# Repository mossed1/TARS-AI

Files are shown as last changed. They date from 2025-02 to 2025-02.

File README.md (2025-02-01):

<h1 align="center">TARS-AI</h2>

<p align="center">
    <a href="https://discord.gg/AmE2Gv9EUt">
      
    </a>
    <a href="https://www.youtube.com/@TARS-AI.py.youtube">
        
    </a>
    <a href="https://www.instagram.com/tars.ai.py">
        
    </a>
    <a href="https://www.tiktok.com/@tars.ai.py">
        
    </a>
</p>

<p align="center"></p>

A recreation of the TARS robot from Interstellar, featuring AI capabilities and servo-driven movement. 

## Table of Contents
- [Hardware Requirements](#hardware-requirements)
- [Software Stack](#software-stack)
- [Build Modifications](#build-modifications)
- [License](#license)
- [Contributing](#contributing)
- [Additional Resources](#additional-resources)

## Hardware Requirements 

Everything here is **under development** and is subject to change.
The buck converter and USB power modules are the most important power components and there are many options depending on your build choices. If you have any questions ping us in the discord electrical channel.

| Category | Component | Description | Link |
|---|---|---|---|
| **Printing** | Bambu Labs Printer | Compatible models: P1S, A1, X1C | - |
| | TPU Filament (Bambu) | For all "Flexor" parts | [Buy](https://us.store.bambulab.com/products/tpu-for-ams) |
| | TPU Filament (Alternative) | Overture TPU filament | [Buy](https://www.amazon.com/Overture-Filament-Flexible-Consumables-Dimensional/dp/B07VDP2S3P/) |
| | PETG Filament | For all non-Flexor parts | [Buy](https://us.store.bambulab.com/products/petg-hf) |
| | PLA Filament | Optional - for rapid prototyping | - |
| **Core Components** | Raspberry Pi 5 | Main computing unit | [Buy](https://www.amazon.com/Raspberry-Pi-Quad-core-Cortex-A76-Processor/dp/B0CTQ3BQLS/) |
| | 3.5" LCD Display | Interface display | [Buy](https://www.amazon.com/OSOYOO-3-5inch-Display-Protective-Raspberry/dp/B09CD9W6NQ/) |
| | 16-Channel PWM Servo Driver | I2C Interface | [Buy](https://www.amazon.com/gp/product/B00EIB0U7A/) |
| **Power Components** | Buck Converter | Power management | [Buy](https://www.amazon.com/gp/product/B07SGJSLDL/) |
| | USB power | 2x for Pi and display. Must have 5A minimum to drive a Raspberry Pi 5.| [Buy](https://www.amazon.com/gp/product/B07X5H4M42) |
| | Single LiPo Battery| 11.1v 3S 2200mAh| [Buy](https://www.amazon.com/gp/product/B0BYNSH6Q7) |
| | Wire Connectors| PCT-214 (optionally clips into v9 lower lid)| [Buy](https://www.amazon.com/smseace-Conductor-Connectors-Connection-Terminal/dp/B087PBHG9L) |
| **Servo Motors** | diymore MG996R | Digital servo motors (2x 90g servos per leg) | [Buy](https://www.amazon.com/diymore-6-Pack-MG996R-Digital-Helicopter/dp/B0CGRP59HJ/) |
| | MG996R 55g (Alternative to above) | Digital 55g high torque (2x per leg) | [Buy](https://www.amazon.com/gp/product/B0BMM1G74B) |
| | Micro servos (hands) | Digital servo motors (2x S51/9g micro servos per arm/hand) | [Buy](https://www.amazon.com/gp/product/B07L2SF3R4/) |
| **Drive Train** | Bearings | Motion support | [Buy](https://www.amazon.com/gp/product/B07FW26HD4/) |
| | Springs | Motion dampening | [Buy](https://www.amazon.com/gp/product/B076M6SFFP/) |
| | Metal Rods (Option 1) | Structural support | [Buy](https://www.amazon.com/gp/product/B01MAYQ12S/) |
| | Metal Rods (Option 2) | Alternative structural support | [Buy](https://www.amazon.com/gp/product/B0CTSX8SJS/) |
| | Linkage | Motion transfer | [Buy](https://www.amazon.com/gp/product/B0CRDRWYXW/) |
| | Servo Extension Wires | Connection cables | [Buy](https://www.amazon.com/OliYin-7-87in-Quadcopter-Extension-Futaba/dp/B0711TBZY2/) |
| **Audio System** | Raspberry Pi Microphone | Audio input | [Buy](https://www.amazon.com/gp/product/B086DRRP79/) |
| | Audio Amplifier | Sound processing | [Buy](https://www.amazon.com/dp/B0BTBS5NW2) |
| | Speaker | Audio output | [Buy](https://www.amazon.com/dp/B07GJ4GH67) |
| **Camera System** | Camera Module | Visual input | [Buy](https://a.co/d/50BbE8a) |
| | Camera Ribbon Cable | Camera connection | [Buy](https://www.amazon.com/Onyehn-Raspberry-Camera-Cable-Ribbon/dp/B07XZ5DX5H/) |
| **Fasteners** | M3 20mm Screws | Mounting (6x needed) | [Buy](https://www.amazon.com/gp/product/B0CR6DY4SS/) |
| | M3 14mm Screws | Mounting (40x needed) | [Buy](https://www.amazon.com/gp/product/B0D9GW9K4G/) |
| | M3 10mm Screws | Mounting (76x needed) | [Buy](https://www.amazon.com/gp/product/B0CR6G5XWC/) |
| | M3 Asstd Grub Screws | Mounting (6-8 needed) | [Buy](https://www.amazon.com/dp/B07N7C6HKP/) |
| | M2.x self tapping | Pi and servo controller mounts (8 needed) | [Buy](https://www.amazon.com/gp/product/B0BLY1MPLR/) |

## Wiring Guide for GPIO LCD Screen (if not using HDMI) and I2S Amplifier.
This section provides detailed instructions on how to wire an LCD display and an I2S amplifier to a Raspberry Pi, along with steps to calibrate the touchscreen and fine-tune the display. It assumes you are using an SPI-based LCD screen and an I2S amplifier for audio output.

---

## LCD Wiring

To wire the LCD display to your Raspberry Pi, use the following pinout configuration:

| **LCD Pin** | **Raspberry Pi GPIO Pin** | **Description** |
|---|---|---|
| 1, 17 | 3.3V (Pin 1 or 17) | 3.3V power supply. |
| 2, 4 | 5V (Pin 2 or 4) | 5V power supply for the backlight (if required). |
| 6, 9, 14, 20, 25  | GND (Pin 6, 9, etc.) | Ground connections. |
| 11 | GPIO17 (Pin 11) | Touch IRQ (optional, for touch input). |
| 18 | GPIO24 (Pin 18) | LCD Register Select (DC/RS). |
| 19 | GPIO10 (Pin 19, SPI MOSI) | SPI MOSI (data sent to the LCD). |
| 21 | GPIO9 (Pin 21, SPI MISO)  | SPI MISO (data received from touchscreen). |
| 22 | GPIO25 (Pin 22) | LCD Reset pin. |
| 23 | GPIO11 (Pin 23, SPI SCLK) | SPI Clock for LCD and touchscreen. |
| 24 | GPIO8 (Pin 24, SPI CE0) | SPI Chip Select for LCD. |
| 26 | GPIO7 (Pin 26, SPI CE1) | SPI Chip Select for touchscreen. |

---

## Connecting the I2S Amplifier

For audio output, connect an I2S amplifier to the Raspberry Pi’s I2S (PCM) pins as follows:

| **Raspberry Pi Pin** | **GPIO Pin** | **Function** | **Connect to Amplifier** |
|---|---|---|---|
| Pin 12 | GPIO18 | I2S Bit Clock (BCLK) | BCLK |
| Pin 35 | GPIO19 | I2S Left/Right Clock (LRCLK) | LRCLK |
| Pin 40 | GPIO21 | I2S Data Out (DOUT) | DIN (Audio Data Input to Amplifier) |
| Pin 6 | GND | Ground | GND (Amplifier Ground) |
| Pin 2 or 4 | 5V | Power Supply | VIN (Amplifier Power Input) |

**Note**: Enable the I2S interface on the Raspberry Pi by following the instructions in the [Adafruit MAX98357 guide](https://learn.adafruit.com/adafruit-max98357-i2s-class-d-mono-amp/pi-i2s-tweaks).

---

## Connecting the 12CH PWM Servo Controller

| **Controller Pin** | **Raspberry Pi GPIO Pin** | **Description** |
|---|---|---|
| GND | GND (Pin 6, etc.) | Ground connection. |
| SCL | SCL (Pin 5) | Serial Clock Line for I2C communication. |
| SDA | SDA (Pin 3) | Serial Data Line for I2C communication. |
| VCC | 3.3V (Pin 1 or 17) | Power for the I2C logic. |

**Note**: Ensure I2C is enabled on your Raspberry Pi using `raspi-config`. If you need help setting that up, let me know!

## Touchscreen Calibration
To calibrate the touchscreen, follow these steps:

### Step 1: Install the Calibration Tool
sudo apt-get update
sudo apt-get install xinput-calibrator

### Step 2: Run the Calibration Tool
xinput_calibrator
Touch the targets as instructed. The tool will generate calibration offsets.

### Step 3: Save the Calibration Data
Save the output data to a configuration file:

sudo nano /usr/share/X11/xorg.conf.d/99-calibration.conf
Paste the calibration data and save the file.

### Step 4: Reboot
sudo reboot

### Step 5: Verify Calibration
Interact with the desktop to ensure accurate touch. If needed, rerun the calibration tool or manually adjust the values in 99-calibration.conf.

**Additional Notes**
- Enable SPI and I2S interfaces via sudo raspi-config under Interfacing Options.
- Refer to the [Adafruit MAX98357 guide](https://cdn-learn.adafruit.com/downloads/pdf/adafruit-max98357-i2s-class-d-mono-amp.pdf) for detailed amplifier setup.
- Test the audio and touchscreen thoroughly after setup.

## Software Stack

See [`ENVSETUP.md`](./ENVSETUP.md) for instructions on setting up the software environment.

GPTARS Software Demo (https://www.youtube.com/watch?v=4YObs8BV3Mc)

- **LLM**: Choice of:
  - OpenAI (Recommended)
  - OpenAI compatibility API (LM Studio, Oobabooga, etc)
  - Tabby ([tabbyAPI](https://github.com/theroyallab/tabbyAPI))
  - Ollama
- **Text-to-Speech**: Choice of:
  - Azure TTS
  - Local (E-speak)
  - Local (Piper TTS with custom Voice model) (Recommended)
  - XTTSv2 with voice cloning ([xtts-api-server](https://github.com/daswer123/xtts-api-server))
  - Alltalk
- **Speech-to-Text**:
  - Vosk
  - Whisper
  - Externally hosted Whisper
- **Vision Handling**:
  - Saleforce Blip
- **Tool Utilization**:
  - Custom Module Engine 
  - Function Calling (two methods)
  - Stable Diffusion
  - Dall-e
  - Home Assistant
  - Volume Control
  - Persona Settings

## Build Modifications
print
- Modified chassis bottom to accommodate SD card installation (See: "Chassis Bottom (Mod SD CARD).stl")

## License
[CC-BY-NU License](./LICENSE)

## Contributing
See [`CONTRIBUTING.md`](./CONTRIBUTING.md) for instructions on contributing to this project.

## Additional Resources
Inspirations + Credits to:
- [@charliediaz](https://www.hackster.io/charlesdiaz/how-to-build-your-own-replica-of-tars-from-interstellar-224833)
- [@gptars](https://www.youtube.com/@gptars)
- [@poboisvert](https://github.com/poboisvert/GPTARS_Interstellar)
- [@Expl0dingCat](https://github.com/Expl0dingCat/Ame) 

## Attribution 
### TARS Project Attribution Guidelines
As we continue to build and expand upon the TARS project, below are the guidelines for attribution and best practices when sharing or publishing work related to the TARS project:

#### General Attribution
- Clearly state that this project is based on the character TARS from the film *Interstellar*.
- When referencing or sharing the CAD designs:
  - Include a statement like: “Based on the mechanical puppet designs by Christopher Nolan, Nathan Crowley, and the production team who originally brought TARS to life—miniaturized CAD by Charlie Diaz, with additional modifications by the TARS-AI Community.”

#### Specific Guidelines for CAD and Scripts
- The original CAD files and scripts are provided by Charlie Diaz. If you modify or extend these, ensure to:
  - Credit Charlie Diaz as the original creator of the CAD files.
  - Clearly specify your contributions or modifications.

#### Usage of TARS’ Voice and Personality
  - “This project includes AI-generated elements inspired by Bill Irwin’s portrayal of TARS in the film *Interstellar*.”

#### Sharing Content Online
- When publishing content (e.g., YouTube videos, blog posts, or repository updates):
  - Attribute the original film’s production team and Charlie Diaz where applicable.
  - Include a disclaimer noting that this project is a fan-made initiative.

#### Legal Considerations
- Monetization is strictly prohibited.

#### Community Contribution
- Encourage contributors to follow these attribution guidelines when making modifications or additions to the project.
- Foster an open and respectful community by maintaining transparency in crediting the work of all contributors.

These guidelines ensure that the TARS project respects the intellectual property of the original creators while fostering a collaborative and innovative community. Let’s work together to keep this project thriving and inspiring!

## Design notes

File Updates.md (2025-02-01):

### TARS-AI 2.0 Development Branch Update

The TARS-AI 2.0 development branch introduces several enhancements over the initial 1.0 release, including:

---

#### :rocket: **Core Additions**  

**Speech-to-Text (STT) Enhancements:**  
- Integrated **Whisper** for local STT alongside **Vosk** and external server options.  
- Added STT sensitivity configuration for improved accuracy.  
- Comprehensive improvements to the STT system for better transcription.  
- Significant speed improvements.  
- Dynamic microphone quality selection based on hardware.  

**Character Customizations:**  
- Persistent personality settings (e.g., humor and tone) for dynamic character interaction.  
- Expanded character settings and behavior customization options.  

**Function Calling:**  
- Dual methods for function calls: **Naive Bayes (NB)** and **LLM-based approaches**.  

**Voice-Controlled Movement:**  
- Enabled voice commands to control robotic movements with precise mapping.  

**Image Generation:**  
- Integrated **DALL·E** and **Stable Diffusion** for AI-powered image creation.  

**Volume Control:**  
- Fine-tuned volume adjustments through both voice commands and external configurations. **Credit: @mskull**  

**Home Assistant Integration:**  
- Seamless connection with smart home systems.  

---

#### :gear: **Technical Improvements**

- **Reworked LLM function** into its own module.  
- **Reworked LLM function** to be compatible with thinking models (Deepseek R1).  
- **Reworked build prompt function** for easy importing.  
- **Reworked memory module** to ensure correct prompt and memory management.  
- **Reworked tokenization** for proper counts.  
- **Renamed STL files** for better readability.  
- **Many fixes and tweaks** for better usability.  
- Over **196 commits**.  

**Override Encoding Model:**  
- Enhanced compatibility with models using `override_encoding_model`.  

**TTS Fixes:**  
- Resolved issues with special characters in Text-to-Speech.  

---

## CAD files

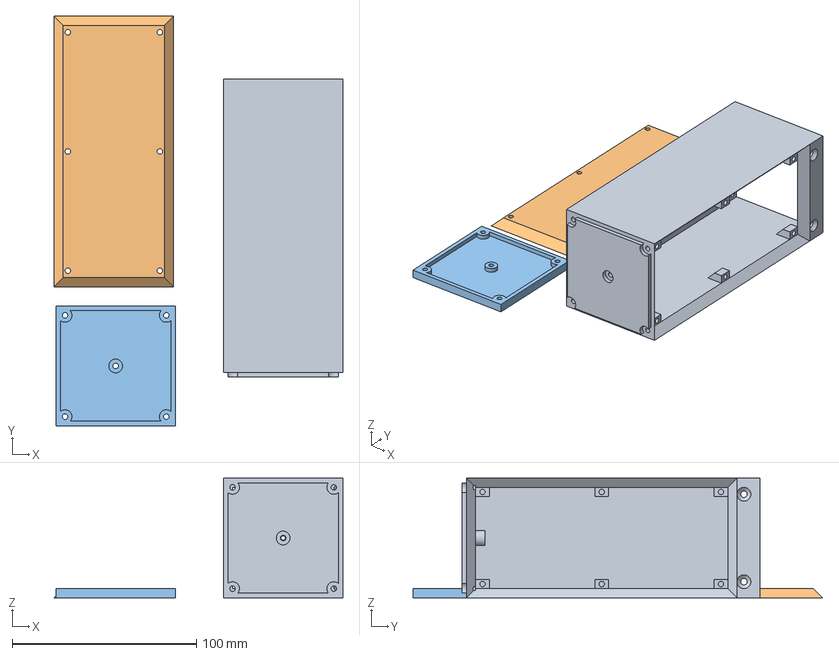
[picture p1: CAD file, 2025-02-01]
3d Printer Files/simplified_tars/footpad-simplified.3mf
156.9 x 222.5 x 65.0 mm
leg - simplified.stl
leg_simplified-lid.stl
footpad-simplified.stl

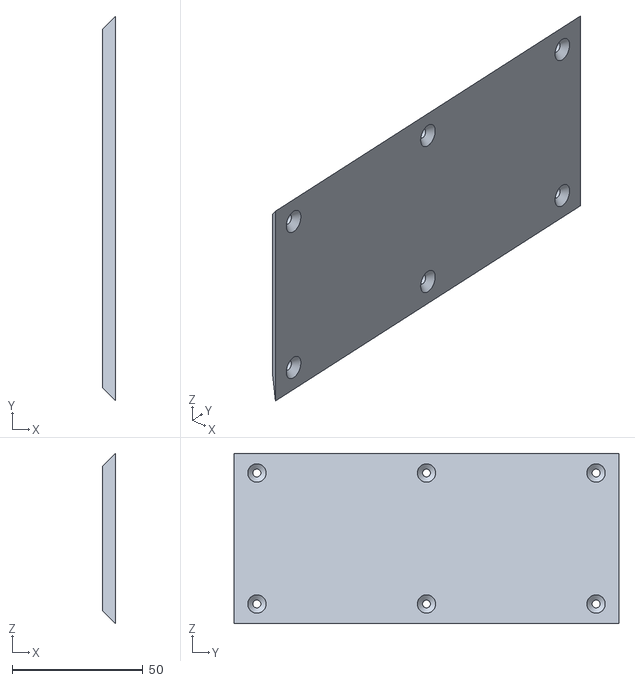
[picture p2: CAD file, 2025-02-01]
3d Printer Files/simplified_tars/leg_simplified-lid.stl
5.00 x 147.0 x 65.0

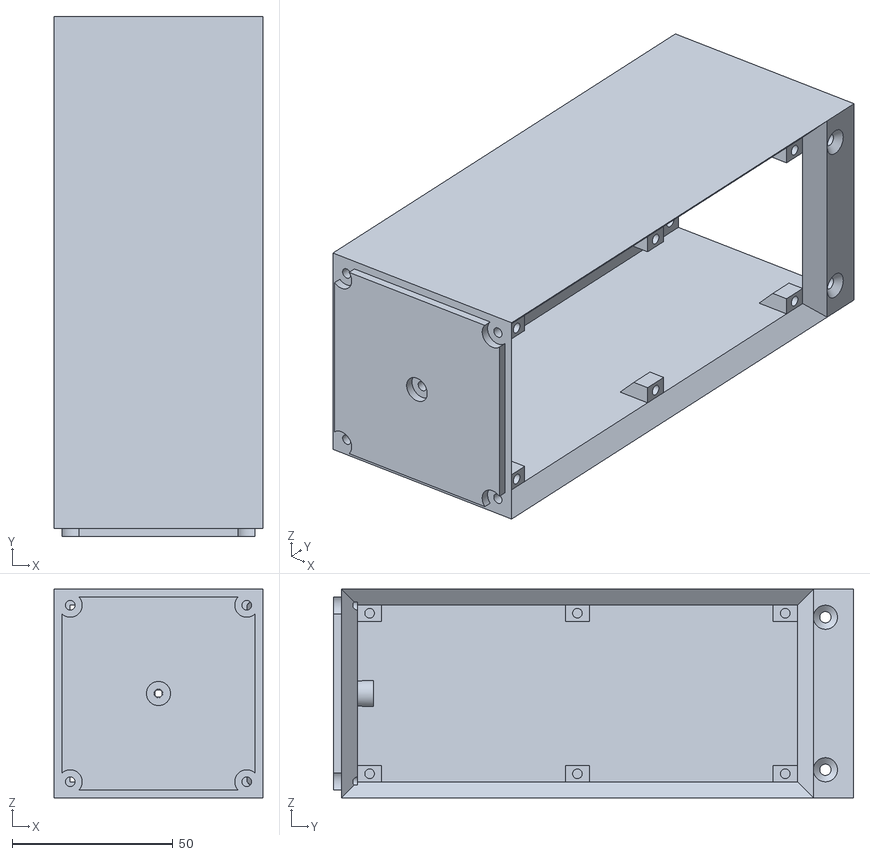
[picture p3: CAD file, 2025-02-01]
3d Printer Files/simplified_tars/leg - simplified.stl
65.0 x 162.0 x 65.0

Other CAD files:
3d Printer Files/simplified_tars/footpad-simplified.stl

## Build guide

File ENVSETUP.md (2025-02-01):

# ENVSETUP.md

## Minimum Hardware Prerequisites

1. **Raspberry Pi**: For obvious reasons.
2. **USB Microphone**: For user input.
3. **Speaker**: For TARS output.

---

## Environment Setup Guide (IN DEVELOPMENT)

### 1. Set Up the TARS-AI Repository on Raspberry Pi

#### A. Clone the Repository
1. Open a terminal on your Raspberry Pi.
2. Clone the **TARS-AI** repository:
   ```bash
   git clone https://github.com/pyrater/TARS-AI.git
   ```
3. Navigate to the cloned directory:
   ```bash
   cd TARS-AI
   ```

#### B. Install System-Level Dependencies
These dependencies are required for various operations, including Selenium-based automation, audio processing, and format handling.

1. **Update Your System**:
   Ensure your package lists and installed software are up to date:
   ```bash
   sudo apt update
   sudo apt upgrade -y
   ```

2. **Install Chromium**:
   Chromium is the browser required for Selenium-based web automation:
   ```bash
   sudo apt install -y chromium-browser
   ```

3. **Install Chromedriver for Selenium**:
   Chromedriver allows Selenium to control Chromium:
   ```bash
   sudo apt install -y chromium-chromedriver
   ```

4. **Install SoX and Format Support Libraries**:
   SoX is a command-line tool for processing audio files. 
   ```bash
   sudo apt install -y sox libsox-fmt-all
   ```

5. **Install PortAudio Development Libraries**:
   PortAudio is a cross-platform audio input/output library.
   ```bash
   sudo apt install -y portaudio19-dev
   ```

6. **Verify Installations**:
   Confirm that the installed packages are functioning:
   - Check Chromium version:
     ```bash
     chromium-browser --version
     ```
   - Check Chromedriver version:
     ```bash
     chromedriver --version
     ```
   - Check SoX version:
     ```bash
     sox --version
     ```

#### C. Set Up the Python Environment

1. Create a virtual environment:
   ```bash
   python3 -m venv venv
   ```
2. Activate the virtual environment:
   ```bash
   source venv/bin/activate
   ```
3. Install the required dependencies under `src/`:
   ```bash
   pip install -r requirements.txt
   ```

#### D. Connect Hardware

1. Connect your **microphone** to the Raspberry Pi via USB.
2. Connect your **speaker** to the Raspberry Pi using the audio output or Bluetooth.

#### E. Set the API Key in a `.env` File (Recommended for Secure Key Management)

**Create** a `.env` file at the root of your repository based on the pre-existing .env.template file to store your API keys for your LLM and TTS service.

**`.env` Template**:
   Add the following lines to your `.env` file. Replace `your-actual-api-key` with your actual API key for the desired service:
   ```env
   # LLM
   OPENAI_API_KEY="your-actual-openai-api-key"
   OOBA_API_KEY="your-actual-ooba-api-key"
   TABBY_API_KEY="your-actual-tabby-api-key"

   # TTS
   AZURE_API_KEY="your-actual-azure-api-key"
   ```
   - Set up an OpenAI API Key (very small cost) - [OpenAI API Key](https://www.youtube.com/watch?v=OB99E7Y1cMA)
   - Set up an Azure Speech API Key (FREE) - [Azure Speech API Key](https://www.youtube.com/watch?v=e4_AytZ264Q)
      - Make sure to create a Free Azure account [Free Azure Signup](https://azure.microsoft.com/en-us/pricing/purchase-options/azure-account?icid=azurefreeaccount)
      - Follow all the steps in the video up to `Install Azure speech Python package`.

#### F. Set the config.ini Parameters 

1. **Create** a `config.ini` file in the `src/` folder based on the pre-existing config.ini.template file.

2. Locate the `[LLM]` section and update the parameters (for OpenAI):
   ```ini
   [LLM] # Large Language Model configuration (ooba/OAI or tabby)
   llm_backend = openai
   # Set this to `openai` if using OpenAI models.
   base_url = https://api.openai.com
   # The URL for the OpenAI API.
   openai_model = gpt-4o-mini
   # Specify the OpenAI model to use (e.g., gpt-4o-mini or another supported model).
   ```

3. Locate the `[TTS]` section and update the parameters:
   ```ini
   [TTS] # Text-to-Speech configuration 
   ttsoption = azure
   # TTS backend option: [azure, local, xttsv2, TARS]
   azure_region = eastus
   # Azure region for Azure TTS (e.g., eastus)
   ...
   tts_voice = en-US-Steffan:DragonHDLatestNeural
   # Name of the cloned voice to use (e.g., TARS2)
   ```
- `tts_voice`: You can find other voices available with Azure [here](https://learn.microsoft.com/en-us/azure/ai-services/speech-service/language-support?tabs=tts).
   - If en-US-Steffan:DragonHDLatestNeural gives you an error, try en-US-SteffanNeural.

#### G. Run the Program
1. Navigate to the `src/` folder within the repository:
   ```bash
   cd src/
   ```
2. Start the application:
   ```bash
   python app.py
   ```
3. The program should now be running and ready to interact using your microphone and speaker.

## (OPTIONAL) Set up XTTS Server

### 1. Prepare Your PC with NVIDIA GPU
The TTS server must run on your GPU-enabled PC due to its computational requirements.

1. Ensure **Python 3.9-3.12** is installed on your PC.
2. Install **CUDA** and **cuDNN** compatible with your NVIDIA GPU - [CUDA Installation](https://www.youtube.com/watch?v=krAUwYslS8E)
3. Install **PyTorch** compatible with your CUDA and cuDNN versions - [PyTorch Installation](https://pytorch.org/get-started/locally/)

---

### 2. Set Up XTTS API Server

#### A. Install XTTS API Server
Run the following command on your GPU-enabled PC to clone the [XTTS API Server repository](https://github.com/daswer123/xtts-api-server):

```bash
git clone https://github.com/daswer123/xtts-api-server.git
```

Follow the installation guide for your operating system:
- **Windows**:
  1. Create and activate a virtual environment:
     ```bash
     python -m venv venv
     venv\Scripts\activate
     ```
  2. Install xtts-api-server:
     ```bash
     pip install xtts-api-server
     ```

For more details, refer to the official [XTTS API Server Installation Guide](https://github.com/daswer123/xtts-api-server/tree/main).

#### B. Add the TARS.wav Speaker File
1. Download the `TARS-short.wav` and `TARS-long.wav` files from the `TARS-AI` repository under `src/tts/wakewords
/VoiceClones`. These will be the different voices you can use for TARS.
2. Place it in the `speakers/` directory within the XTTS project folder. If the directory does not exist, create it.

#### C. Start the XTTS API Server
1. Open a terminal in the `xtts-api-server` project directory.
2. Activate your virtual environment if not already active:
3. Start the XTTS API Server:
   ```bash
   python -m xtts_api_server --listen --port 8020
   ```
4. Once the server is running, open a browser and navigate to:
   ```
   http://localhost:8020/docs
   ```
5. This will open the API's Swagger documentation interface, which you can use to test the server and its endpoints.

#### D. Verify the Server
1. Locate the **GET /speakers** endpoint in the API documentation.
2. Click **"Try it out"** and then **"Execute"** to test the endpoint.
3. Ensure the response includes the `TARS-Short` and `TARS-Long` speaker files, with entries similar to:
   ```json
   [
     {
       "name": "TARS-Long",
       "voice_id": "TARS-Long",
       "preview_url": "http://localhost:8020/sample/TARS-Long.wav"
     },
     {
       "name": "TARS-Short",
       "voice_id": "TARS-Short",
       "preview_url": "http://localhost:8020/sample/TARS-Short.wav"
     }
   ]
   ```
4. Locate the **POST /tts_to_audio** endpoint in the API documentation.
5. Click **"Try it out"** and input the following JSON in the **Request Body**:
   ```json
   {
       "text": "Hello, this is TARS speaking.",
       "speaker_wav": "TARS-Short",
       "language": "en"
   }
   ```
6. Click **"Execute"** to send the request.
7. Check the response for a generated audio file. You should see a download field where you can download and listen to the audio output.

# Home Assistant Integration for TARS
This documentation outlines the integration of the TARS AI Assistant with Home Assistant, enabling automated voice-activated function calls.

## Overview
The integration allows TARS to communicate with your Home Assistant setup to automatically process voice commands. It leverages Home Assistant's "Assistant" functionality to send prompts and execute corresponding actions.

## Prerequisites
1. Ensure that Home Assistant is installed and accessible on your network.
2. Have TARS set up in your environment.
3. A long-lived access token generated from Home Assistant.

## Configuration Steps
Step 1. **Update your `config.ini` file:**
   
   Ensure the Home Assistant module is enabled and configure the URL:
   ```ini
   [HOME_ASSISTANT] # HA Module
   enabled = True
   # If set to False, the Home Assistant module will be disabled.
   url = http://homeassistant.local:8123
   # http://192.168.2.5:8123
   # Url to acccess HA from (set Token in .env file!).
   ```
   Adjust the URL if your Home Assistant is accessible via a different address.

Step 2. **Add HA_TOKEN to `.env`:**
   - Log into Home Assistant.
   - Select your user profile (bottom left).
   - In the Security menu, scroll down to "Long-lived access tokens".
   - Create a new token, name it, and **copy the token**.
   - Add this token to your `.env` file as `HA_TOKEN="INSERT TOKEN HERE"`.

**Note:** Verify the token works before closing the creation dialog.
